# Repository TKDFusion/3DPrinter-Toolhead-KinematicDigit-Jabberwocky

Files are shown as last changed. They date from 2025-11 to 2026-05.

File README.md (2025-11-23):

# Jabberwocky

Jabberwocky Render

**JABBERWOCKY** has been engineered to meet the demanding requirements of filament changing units (FCUs) and multicolor changers. Its extruder is purpose-built to handle the rigorous load and unloading cycles of FCUs, utilizing a Bondtech compound drive gear in an offset configuration, paired with dual LDO non-threaded Orbiter gears for precise and reliable filament control.

The system offers a carefully optimized balance of torque and speed, along with increased surface contact on the filament to ensure stability and consistent feeding throughout operation.

Designed for maximum reliability and serviceability, the toolhead features a tool-free, hinged extruder mechanism, enabling fast and hassle-free maintenance.

Efficient thermal performance is delivered by high-static-pressure fans, ensuring airflow reaches critical areas, while the Phaetus Conch high-flow hotend enables smooth, consistent extrusion at volumes of up to 35 mm³/s.

For complete assembly instructions and additional technical details, please refer to our [Wiki](https://github.com/kinematicdigit/Jabberwocky/wiki).

Kits will be available through LDO Motor's Vendor Channels. Check your favourite vendor for the latest availability.

**OPTIONS**

Currently, there are three types of kits you can purchase.

- Prebuilt Jabberwocky Kit - This is fully assembled at the LDO facility and ready to install in your printer (after you print the correct mounting plate for your printer). It is intended to save time or for less effort. 
- Standard Jabberwocky Kit - Also sometimes referred to as DIY or Unassembled. This is the recommended kit for beginners to advanced users. Visit this [Wiki](https://github.com/kinematicdigit/Jabberwocky/wiki) link for instructions.
- Basic Jabberwocky Kit - This kit allows for self sourcing your own toolhead and tool-board. Great for users that might have the components. It gives flexibility for open development or advanced users who want to use different toolheads and different electronics. Examples like UHF Rapido or Revo toolheads are being actively developed/tested. Visit the discord channel to find out what third-party or independent users have created for the Basic Jabberwocky Kits.

For general support, please visit this [link](https://discord.gg/MPZ4cHm9gm) and visit the Jabberwocky channels. 

---
>**Acknowledgments and Thank You**
>
>*The Jabberwocky project commenced shortly after the release of ERCF V2 in November 2023, directly resulting from my contributions to the ERCF development team. I express my gratitude to my team members, particularly MoggieUK, who has been an exceptional ERCF partner, facilitating the exchange of ideas and addressing challenges related to multi-filament and filament-changing units. The realization of this project was contingent upon the substantial research and development support provided by Jason at LDO Motors. We dedicated numerous months to meticulous material selection, conceptual design, and component identification. Thanks to Dr. Róbert Lőrincz’s for technical assistance and comprehensive responses to my inquiries regarding stepper motors interfacing with ERCF, which also proved highly beneficial for this toolhead, as well as for his pioneering work with the Orbiter gears employed within it. Additionally, Fizzy, another ERCF team member, graciously contributed to the creation of the gorgeous wiki page and documentation, simplifying the user guide for assembling the kit. Finally, I would like to acknowledge the invaluable assistance provided by the many beta testers, who were instrumental in numerous revisions, improvements, and testing conducted during the testing phase.*

>
>*Happy Printing!*
>
>Terrance AKA kinematicdigit
>
Coffee fund donations are always welcome to help support my ongoing efforts. [Click here](https://www.paypal.com/donate/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) to donate. Thank-you!

Shield: [][cc-by-sa]

This work is licensed under a
[Creative Commons Attribution-ShareAlike 4.0 International License][cc-by-sa].

[][cc-by-sa]

[cc-by-sa]: http://creativecommons.org/licenses/by-sa/4.0/
[cc-by-sa-image]: https://licensebuttons.net/l/by-sa/4.0/88x31.png
[cc-by-sa-shield]: https://img.shields.io/badge/License-CC%20BY--SA%204.0-lightgrey.svg

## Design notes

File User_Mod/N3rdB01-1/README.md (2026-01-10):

# Jabberwocky Voron Tap Mods (User_Mod/<your-folder>)

This folder contains two Voron Tap adapter variants and an insert-placement diagram for the generic adapter. Use the files and instructions below to print, install, and (for the Chaotic Labs variant) modify wiring safely.

Files included
- `Jabberwocky CNC VORON TAP adapter.stl` — Generic Voron Tap adapter (requires two 3 mm inserts; see PDF)
- `Jabberwocky NH36_Mounting_Bracket for ChaoticLabCNCTapPobe.stl` — Chaotic Labs / NH36-specific mounting bracket and adapter (wiring-aware)
- `Jabberwocky CNC VORON TAP Adapter.pdf` — Insert location diagram (shows where to place the two 3 mm inserts)
- `README.md` — This file

Which file to use
- Use `Jabberwocky CNC VORON TAP adapter.stl` for a standard Voron Tap installation. This model requires two 3 mm inserts per the PDF.
- Use `Jabberwocky NH36_Mounting_Bracket for ChaoticLabCNCTapPobe.stl` when installing on a Chaotic Labs Voron tap where the Chaotic wiring interferes with the generic adapter. This variant requires wiring modification per the NH36 wiring diagram (see “Wiring modification” below).

Important safety note — wiring & power
- Do not perform any wiring work while the machine is powered or connected to mains.
- If you are not comfortable working with electronics, ask a qualified person to do the wiring changes.
- The Chaotic Labs variant requires wiring changes according to the NH36 wiring diagram. This README contains high-level guidance; explicit wiring steps will be added once the NH36 wiring diagram / pin mapping is reviewed.

Wiring modification — required reference documents
To modify the TAP cable for the NiteHawk (NH36) board you will need both documents:
- NiteHawk-36 toolboard documentation (Nightawk 36 board wiring / pinout):
  https://docs.ldomotors.com/en/Toolboard/nitehawk-36
- CNC Tap Build Guide (ChaoticLab TAP probe manual):
  https://github.com/Chaoticlab/CNC-Tap-for-Voron/blob/951225ebef3c1753b8fc599a90948c430e2c5943/Manual/CNC_VORON_TAP_V2_BUILD_GUIDE_20240222.pdf

How to use these documents together
1. Open both documents side-by-side (or print the relevant pages). Identify:
   - On the TAP manual: connector pinout for the probe end and the wire colors used in the TAP cable.
   - On the NiteHawk-36 doc: the connector pinout for the NH36 input (which pins accept probe signals, power, ground, etc.).
2. Document current wiring:
   - Photograph the existing TAP connector and cable.
   - Label each wire (numbered or color-coded) so you can map original → new locations.
3. Compare pinouts and plan the mapping:
   - For each TAP wire, determine whether it must be moved to a different pin on the NH36, require a different connector, or requires splice/retermination.
4. Prepare tools and materials:
   - Soldering iron and solder or quality crimp connectors
   - Heat shrink tubing
   - Multimeter
   - Tie wraps / adhesive mounts to secure wires
   - Replacement connector housings if required (confirm exact part number from the docs)
5. Implement the mapping carefully (power OFF):
   - Cut and reterminate wires only after confirming your mapping.
   - Use proper strain relief and insulation.
   - Securely fasten the wiring away from moving parts.
6. Verify before powering:
   - Use a continuity/multimeter check to confirm each TAP signal/power/ground is connected to the intended NH36 pin.
   - Confirm no shorts between power and ground.
7. Power on and test:
   - Power the system and test probe functions in a safe mode (manual probe tests, reduced-power checks).
   - Watch for unexpected heating, smoke, or incorrect voltages — power off immediately if detected.

Wiring-modification checklist (safety)
- [ ] Power is disconnected before any work begins.
- [ ] Wires are labelled and photographed before cutting.
- [ ] You have the correct connector housings/pins (if replacing).
- [ ] Solder joints/crimps are insulated with heat shrink.
- [ ] Continuity and voltage checks done before finalizing.
- [ ] Wiring is secured away from moving parts.

Print settings (recommended starting point)
- Material: PLA or PETG (use PETG if the part will see elevated temps)
- Layer height: 0.20 mm
- Infill: 15–25%
- Perimeters (walls): 2–3
- Print temperature: 200–220 °C (PLA) / 230–250 °C (PETG)
- Bed temperature: 60 °C (PLA) / 70–80 °C (PETG)
- Supports: minimal; enable where model shows overhangs >45°
- Orientation: Print the adapter with the main flat face on the bed (see preview in slicer)

Bed height & printer setup — IMPORTANT (applies to both variants)
- Installing these adapters often requires increased clearance between the print bed and the tap/nozzle assembly.
- For example, on an Ender 5 Plus with a standard bed a solid spacer and raising the bed to >23 mm were required to achieve correct clearance.
- After changing bed height, re-level the bed and verify Z offsets and probe/endstop behavior to avoid crashes.

Inserts — the generic adapter
- The generic `Jabberwocky CNC VORON TAP adapter.stl` requires two 3 mm inserts. See `Jabberwocky CNC VORON TAP Adapter.pdf` for exact hole locations.
- Installation notes for heat-set or press-fit inserts are included in this README.

Assembly — generic adapter
1. Clean printed parts and remove supports.
2. Install the two 3 mm inserts per `Jabberwocky CNC VORON TAP Adapter.pdf`.
3. Align adapter to the Voron Tap mount and secure with M3 screws (hand-tighten; do not overtighten).
4. Verify clearance with wiring and moving parts; re-check after first test run.

Chaotic Labs variant — overview and wiring modification
- Purpose: `Jabberwocky NH36_Mounting_Bracket for ChaoticLabCNCTapPobe.stl` repositions/mounts to avoid Chaotic Labs wiring routing.
- Follow the steps above using the two docs linked earlier to map and modify the TAP cable.

Troubleshooting
- Part won’t seat: confirm slicer scaling = 100% and measure printed dimensions. If holes are too small, open by +0.1–0.3 mm.
- Inserts won’t seat: for heat‑set inserts reduce temperature slightly or pre-warm part; for press-fit try reaming slightly larger.
- Wiring issue after install: power down, re-check wire labels and continuity. If unsure, revert changes and get assistance.
- Bed/clearance issues: if your bed requires significant raising, re-check endstop/probe offsets and Z travel limits before applying power.

Files to include in a release
- Include the two .stl files and `Jabberwocky CNC VORON TAP Adapter.pdf`.
- Add photos of the installed parts (top/bottom) and a short installation video if possible.

Credits & license
- Designer: <Your Name / GitHub handle>
- Contributors: list as needed
- License: See repository root LICENSE. If none, consider adding a license (e.g., CC BY-SA 4.0 for models).

Contact / support
- Open an issue in this repo or contact @<your-github-handle> with questions or test-fit reports.

Changelog
- v1.0 — Initial release: `Jabberwocky CNC VORON TAP adapter.stl`, `Jabberwocky NH36_Mounting_Bracket for ChaoticLabCNCTapPobe.stl`, `Jabberwocky CNC VORON TAP Adapter.pdf`, README (updated with bed height and wiring doc links)

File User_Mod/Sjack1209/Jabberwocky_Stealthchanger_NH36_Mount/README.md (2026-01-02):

# Jabberwocky Stealthchanger NH36 Mount

This was designed to properly mount the NiteHawk36 to the Jabberwocky Toolhead while using the Stealtchanger backplate and optical sensor. 

The spacer is not required, but without it the mount sits directly against the back of the extruder stepper.

This is a remix of [https://github.com/DraftShift/StealthChanger/tree/main/UserMods/TheSin-/PCB36_Mount/PCBMount.stl] 
 
<table>
  <tr>
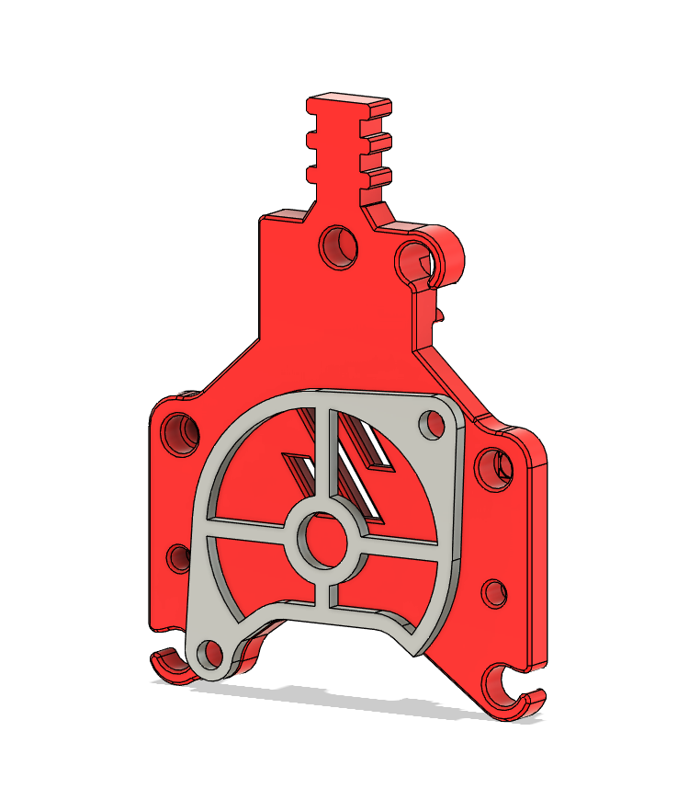
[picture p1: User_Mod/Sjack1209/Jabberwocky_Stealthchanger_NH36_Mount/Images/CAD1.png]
    <td></td>
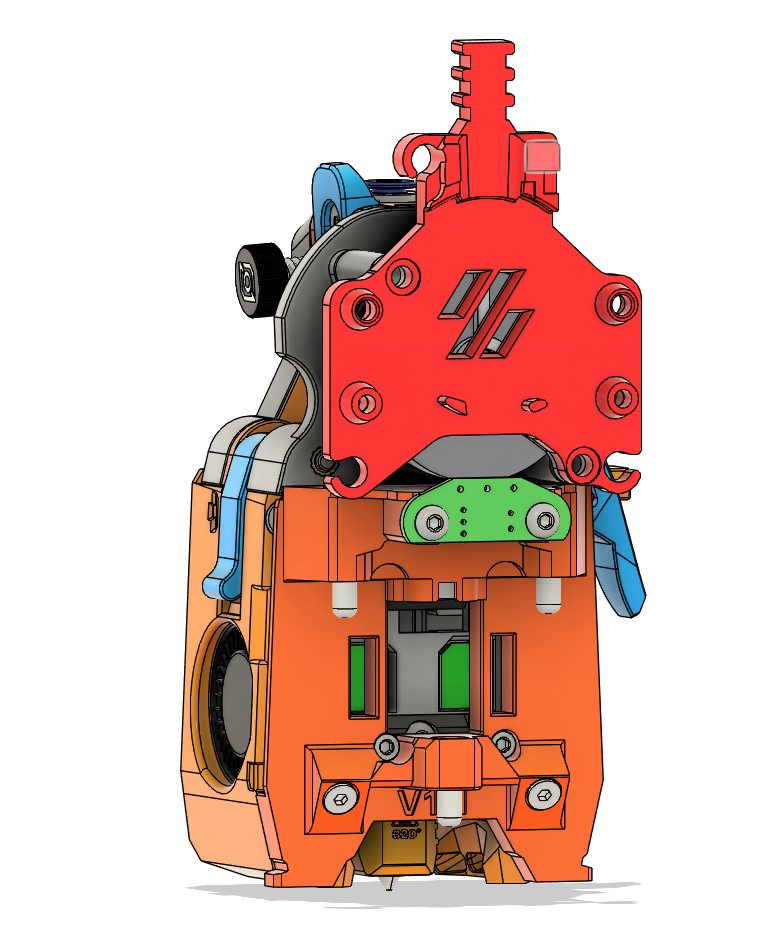
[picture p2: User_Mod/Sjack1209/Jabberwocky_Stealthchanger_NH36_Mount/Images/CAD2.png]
    <td></td>
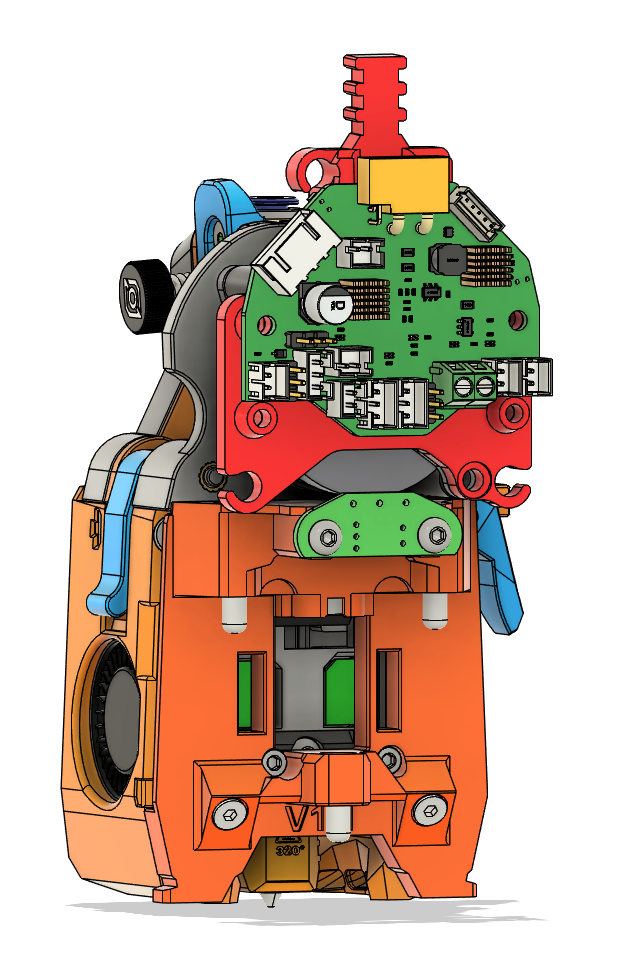
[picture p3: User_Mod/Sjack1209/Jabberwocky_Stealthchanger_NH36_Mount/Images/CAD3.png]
    <td></td>
  </tr>
  <tr>
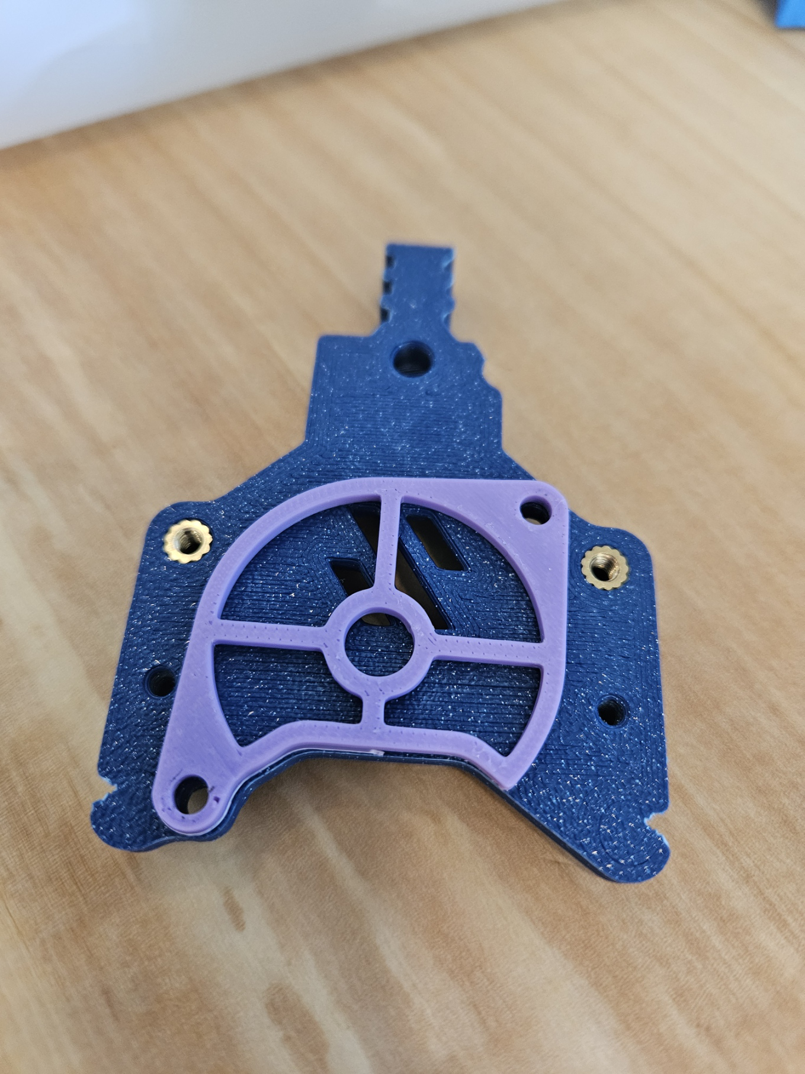
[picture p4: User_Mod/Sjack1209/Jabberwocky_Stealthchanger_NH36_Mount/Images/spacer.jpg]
    <td></td>
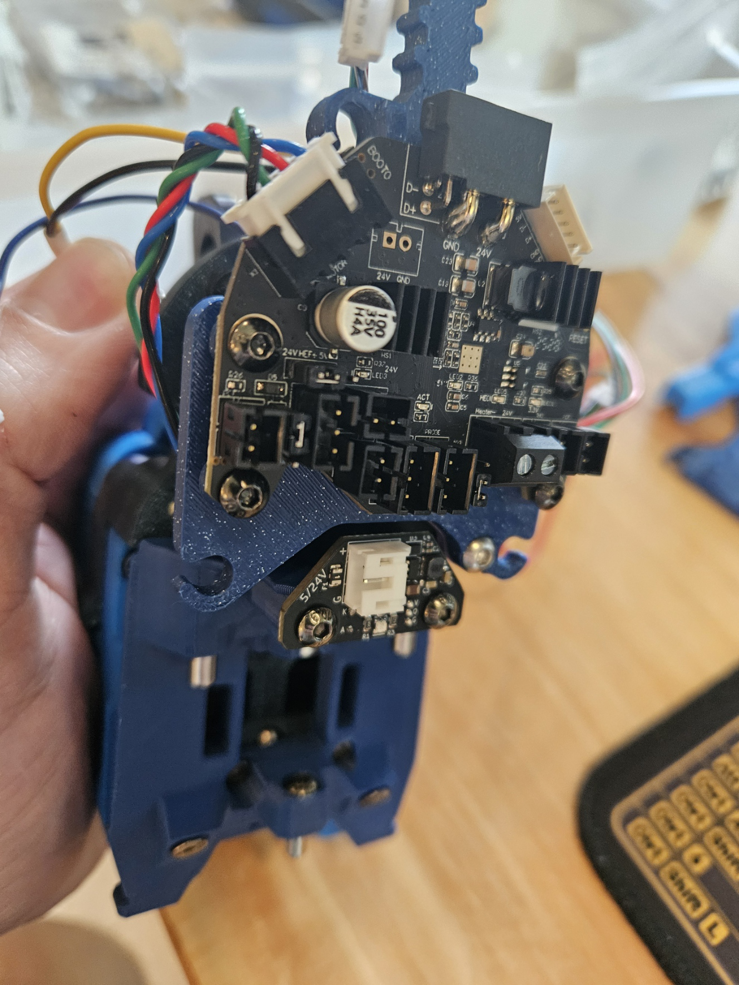
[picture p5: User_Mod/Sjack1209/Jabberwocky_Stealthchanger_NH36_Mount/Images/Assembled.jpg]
    <td></td>
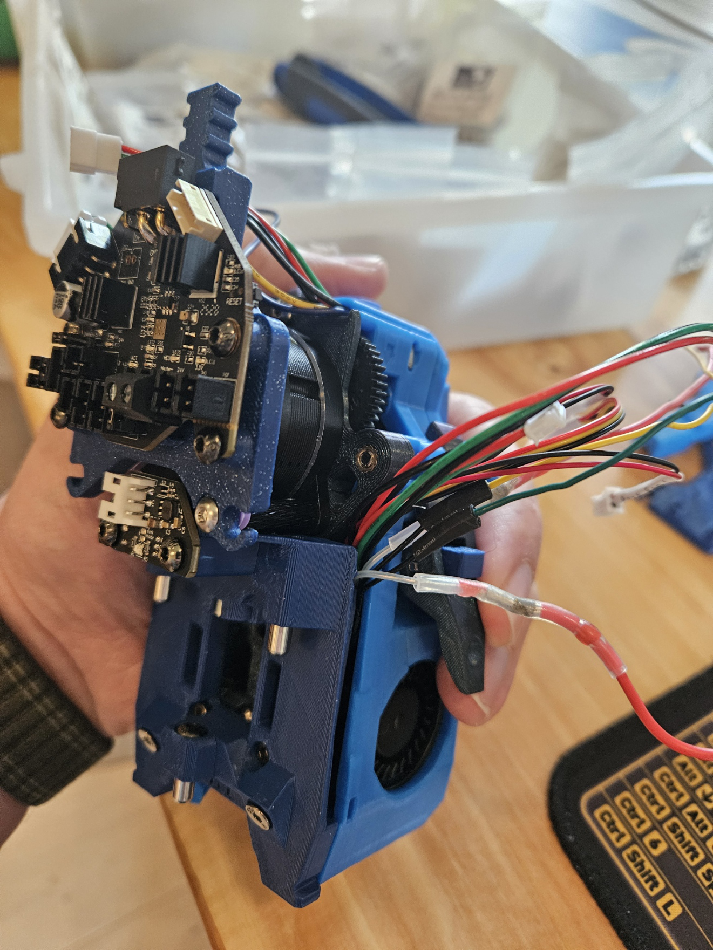
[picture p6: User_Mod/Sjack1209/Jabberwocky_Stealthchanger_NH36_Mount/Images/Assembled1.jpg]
	<td></td>
  </tr>
</table>

## Printing

Use standard voron print settings. 4 walls, 5 top & bottom laters, 40% infill.

## Installation

insert 2 heatset inserts into the back of the mount 

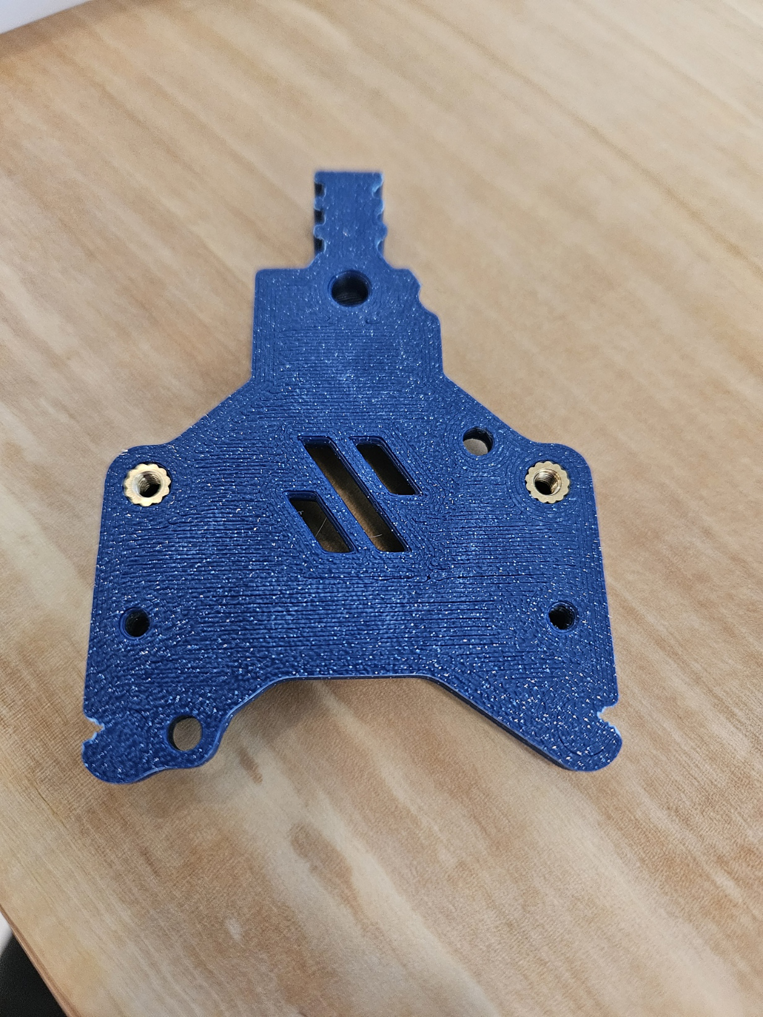
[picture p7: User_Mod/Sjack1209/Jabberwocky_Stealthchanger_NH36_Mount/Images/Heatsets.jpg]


Then attach the mount and spacer to the Toolhead using 2 M3x10 or M3x12 BHCS 

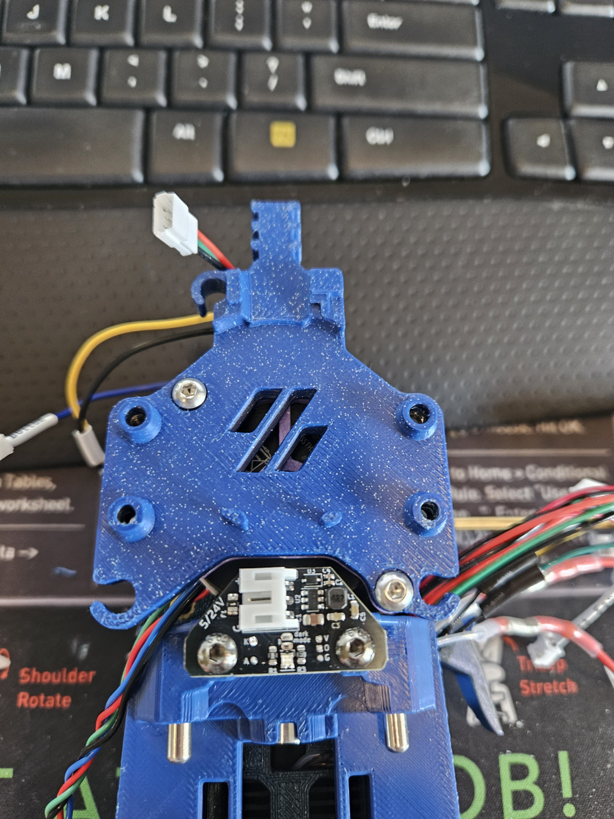
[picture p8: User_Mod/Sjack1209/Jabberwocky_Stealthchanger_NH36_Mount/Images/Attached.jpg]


Next, attach the NH36 with either 2 or 4 M3x8 BHCS



## Bill of Materials (BOM)

qty 2 M3 heatset inserts

## Credits

Thanks to TheSin- for the original PCBMount file that was used.

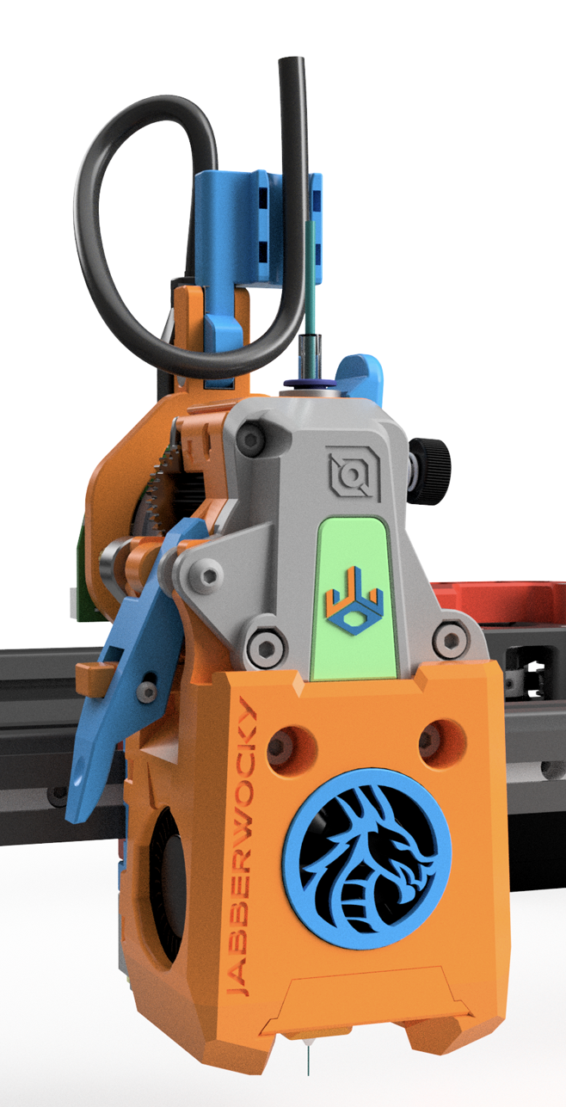
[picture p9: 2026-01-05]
Images/Promo Pic2.png

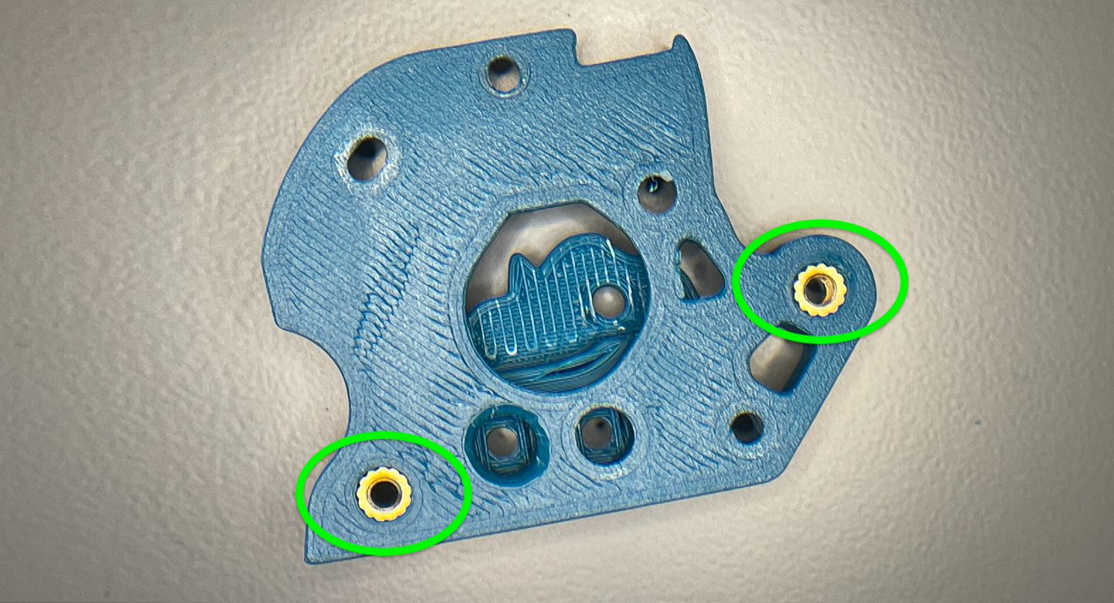
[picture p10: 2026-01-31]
Images/Extruder/Extruder-1_82.png

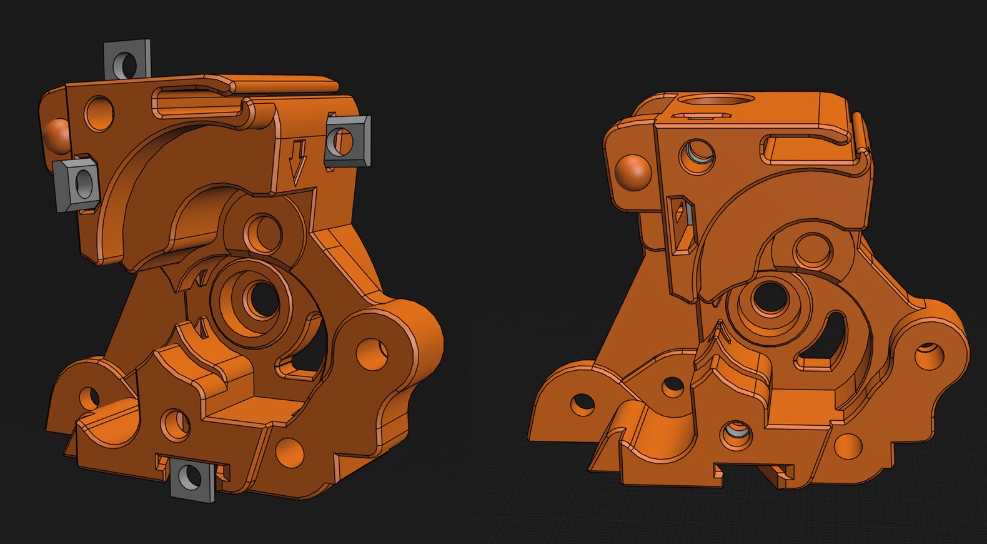
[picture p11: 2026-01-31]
Images/Extruder/Extruder 2.jpg

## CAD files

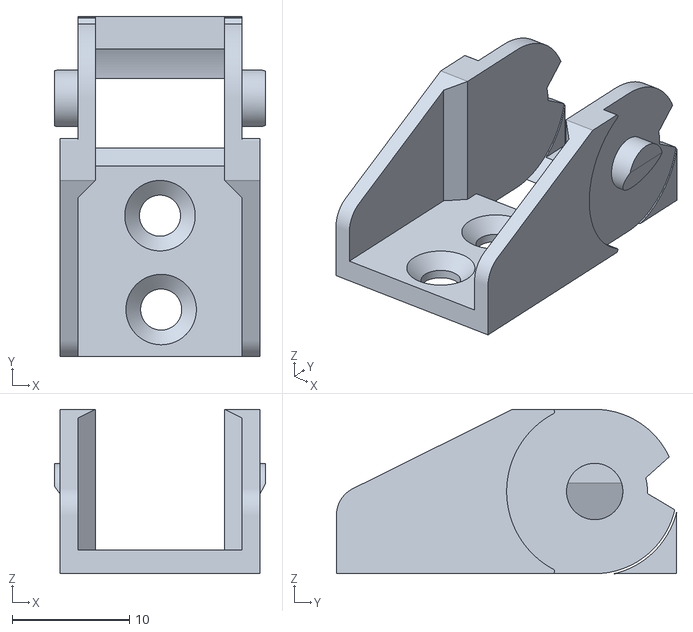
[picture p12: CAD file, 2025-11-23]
Development-testing/drag_chain_support/Chain_Anchor_Fixed_2_hole.stl
18.0 x 29.0 x 14.0

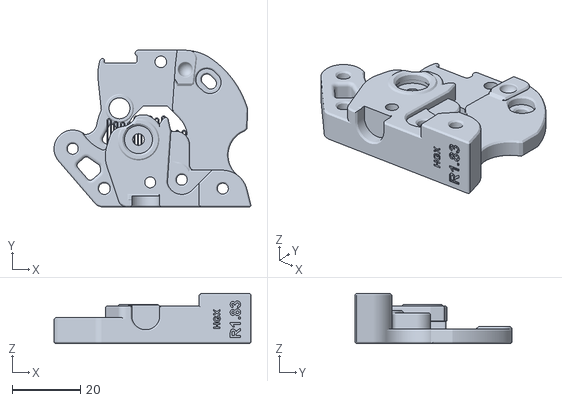
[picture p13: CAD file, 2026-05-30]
Development-testing/HGX-Drive-gear/[a] Motor_Mount_HGX.stl
57.8 x 46.0 x 14.7

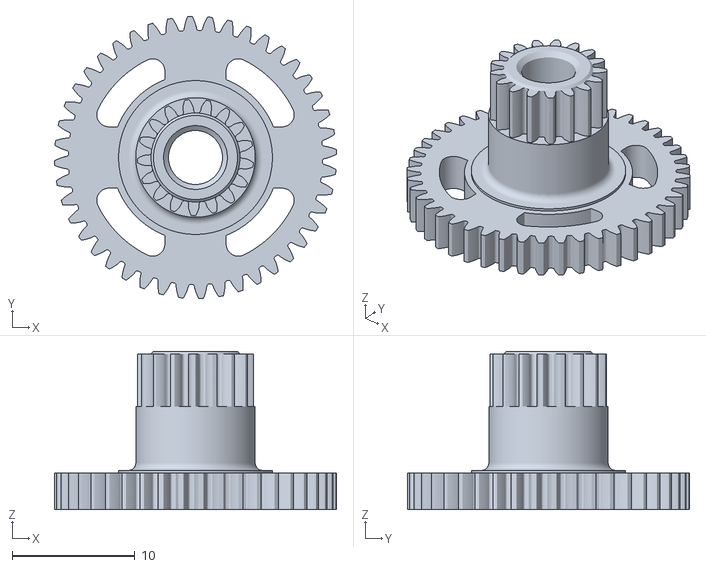
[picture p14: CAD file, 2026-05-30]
Development-testing/printable_drive_gear/Printabe_drive_gear.stl
23.0 x 23.0 x 12.9

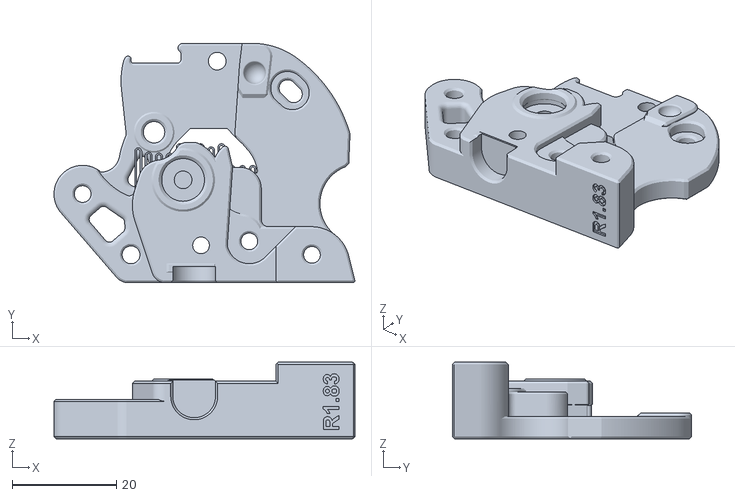
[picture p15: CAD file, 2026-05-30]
Development-testing/R1.83/[a] Motor_Mount.stl
57.8 x 46.0 x 14.7

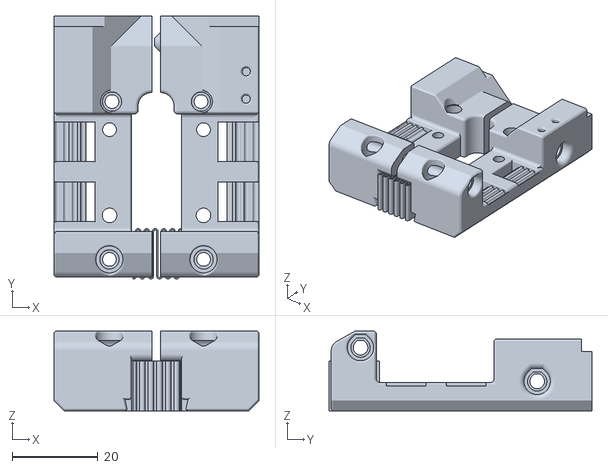
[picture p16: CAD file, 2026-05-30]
Development-testing/SplitMount_MKIV/MGN12-Split_mount_MK4_9mm.stl
47.8 x 61.3 x 18.6

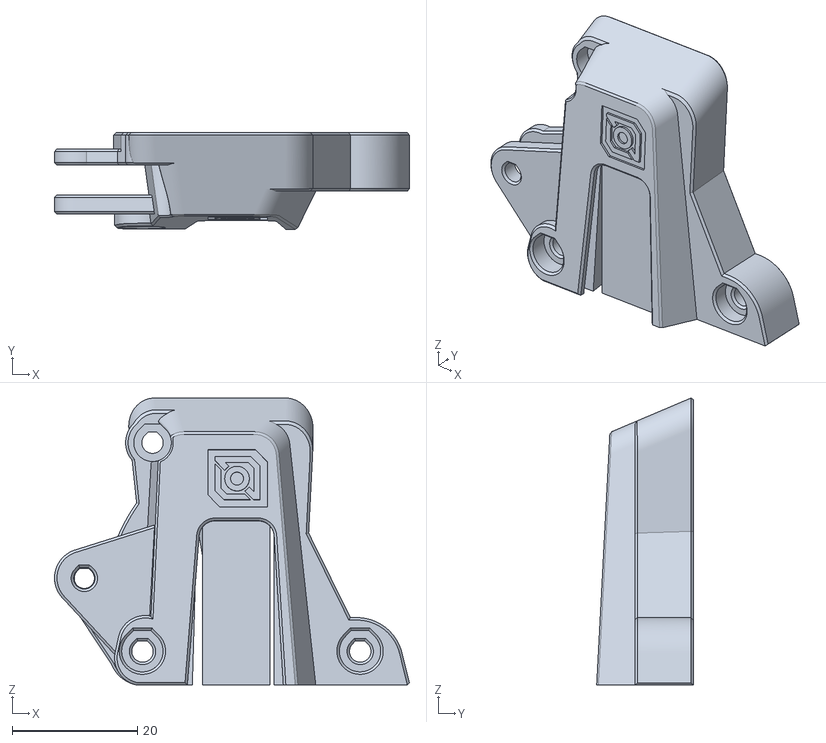
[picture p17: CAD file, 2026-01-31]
Development-testing/V82-RC4/2. Extruder Front Cover/[a] Front_Body.stl
56.7 x 15.4 x 45.8

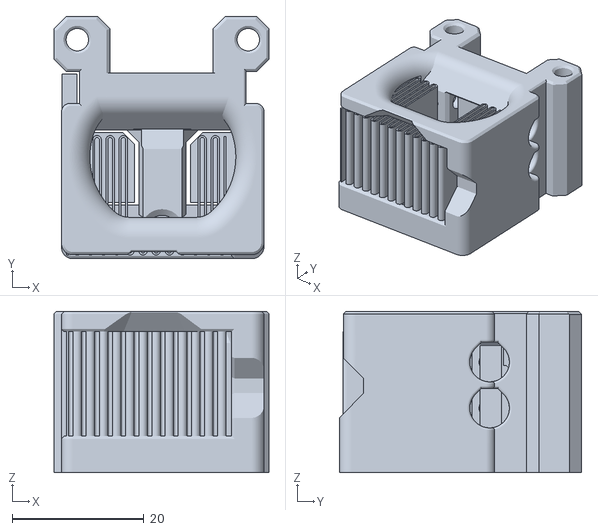
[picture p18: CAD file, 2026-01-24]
Development-testing/V82-RC4/3. Lower Toolhead/[b] Conch_Mount.stl
32.7 x 36.9 x 24.5

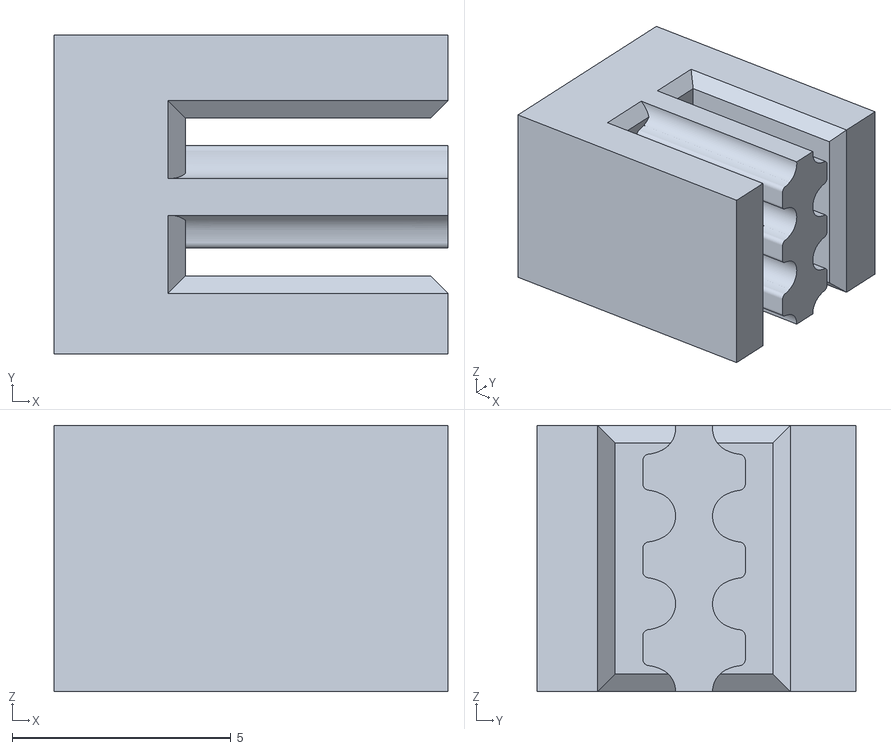
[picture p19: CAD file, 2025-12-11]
Development-testing/V82-RC4/4. Voron 24 - Trident Mounting/belt-lock.stl
9.00 x 7.29 x 6.08

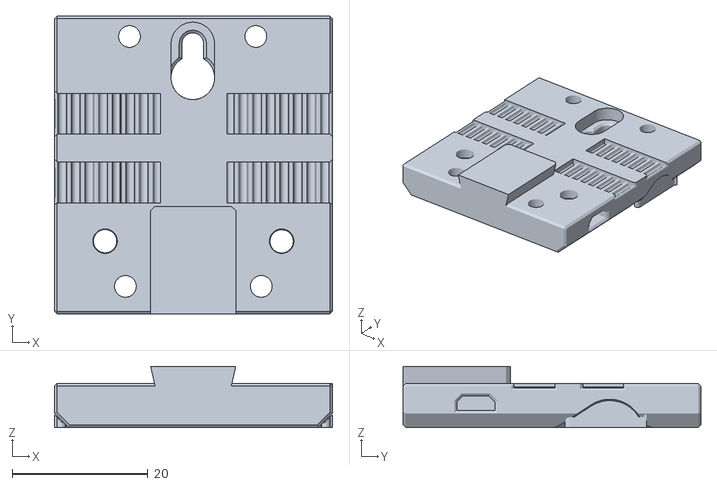
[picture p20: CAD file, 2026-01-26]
Development-testing/V82-RC4/4. Voron 24 - Trident Mounting/split_mount_6mm_belt/MGN12H_Mount_Block_Front.stl
41.0 x 43.9 x 9.03

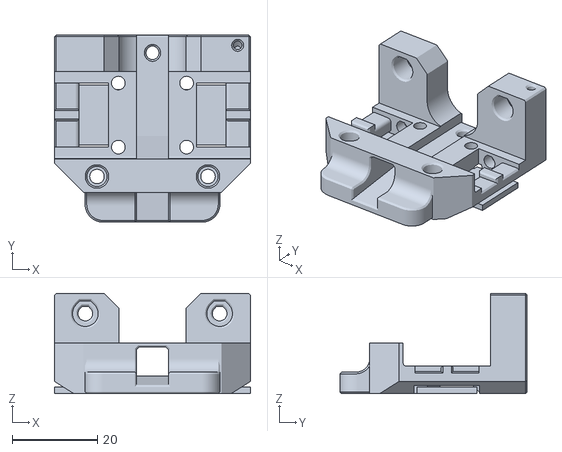
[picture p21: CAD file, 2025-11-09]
Development-testing/V82-RC4/Other_Mounts/Micron/MGN9H_Mount.stl
45.9 x 43.9 x 23.5

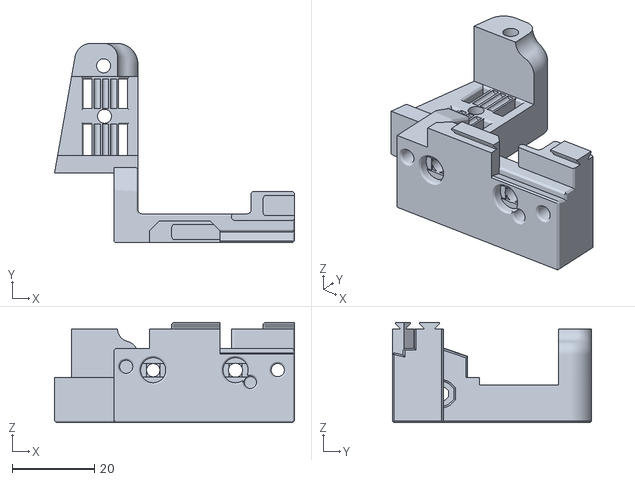
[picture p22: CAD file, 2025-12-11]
Development-testing/V82-RC4/Other_Mounts/Switchwire/SW_Carriage_Right.stl
58.3 x 48.4 x 24.3

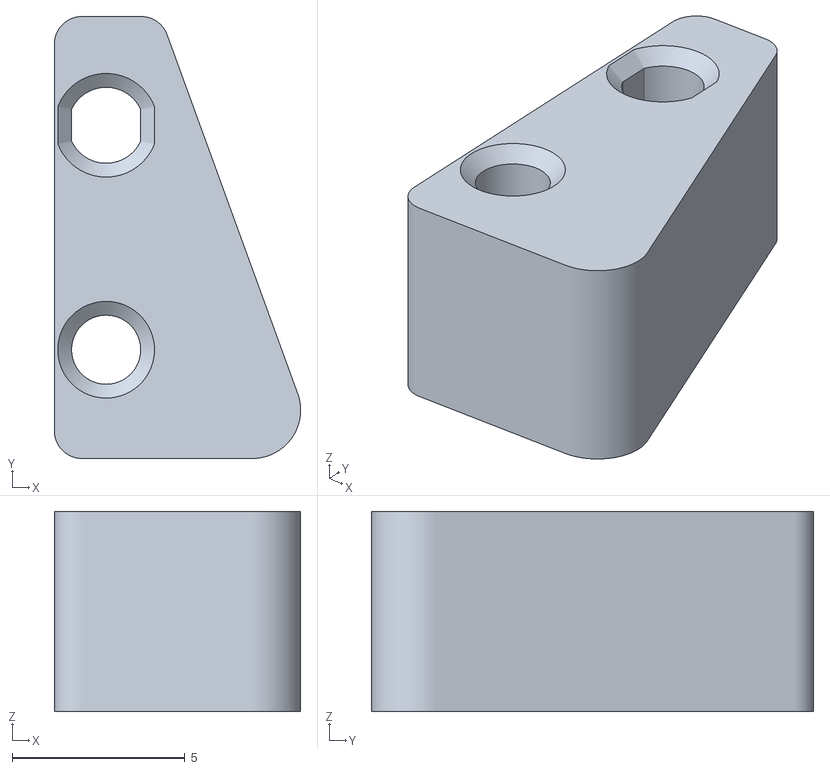
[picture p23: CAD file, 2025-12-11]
Development-testing/V82-RC4/Other_Mounts/X-Sensorless_block_small.stl
7.13 x 12.8 x 5.80

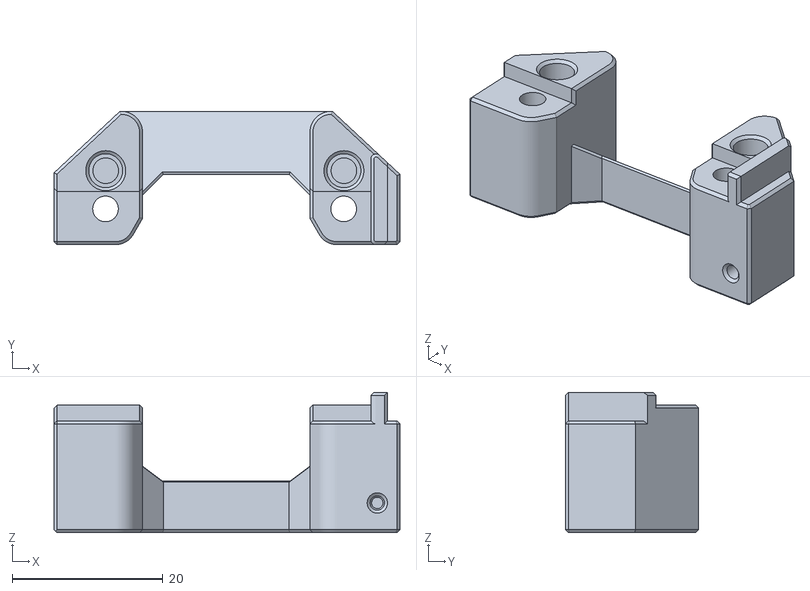
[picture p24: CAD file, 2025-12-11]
Development-testing/V82-RC4/Probes/Carto-Beacon/Carto-Beacon_Mount_Adapter.stl
45.9 x 17.7 x 18.6

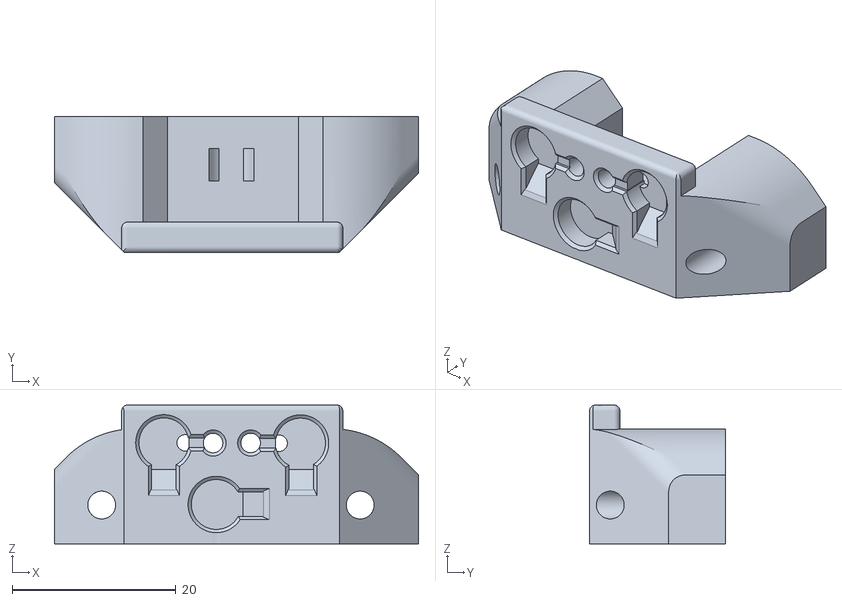
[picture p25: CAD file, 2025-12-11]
Development-testing/V82-RC4/Probes/Klicky/Jabberwocky_Klicky.stl
44.5 x 16.6 x 17.0

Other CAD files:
Development-testing/V82-RC4/Probes/PCB-Klicky/JW_PCB_klicky_mount_adapter.stl
Development-testing/V82-RC4/Tools/Carrot_Puller_Case.stl
STLs/2. Extruder Front Cover/NH36_Mount_Optional_3_column_Support/Hex_standoff-self-thread.stl
STLs/4. Voron 24 - Trident Mounting/split_mount_9mm_belt/MGN12H_Mount_Block_Front_9mm.stl
Development-testing/HGX-Drive-gear/Mid-Body-Base_HGX-ECAS.stl
Development-testing/R1.83/[ab] Guidler.stl
Development-testing/SplitMount_MKIV/MGN12-Split_mount_MK4_6mm.stl
Development-testing/V82-RC4/1. Extruder/Mid_Body_ECAS.stl
Development-testing/V82-RC4/1. Extruder/[a] Motor_Mount.stl
Development-testing/V82-RC4/1. Extruder/[ab] Guidler.stl
Development-testing/V82-RC4/2. Extruder Front Cover/Front_Body_Emount.stl
Development-testing/V82-RC4/2. Extruder Front Cover/NH36_Mounting_Bracket.stl
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

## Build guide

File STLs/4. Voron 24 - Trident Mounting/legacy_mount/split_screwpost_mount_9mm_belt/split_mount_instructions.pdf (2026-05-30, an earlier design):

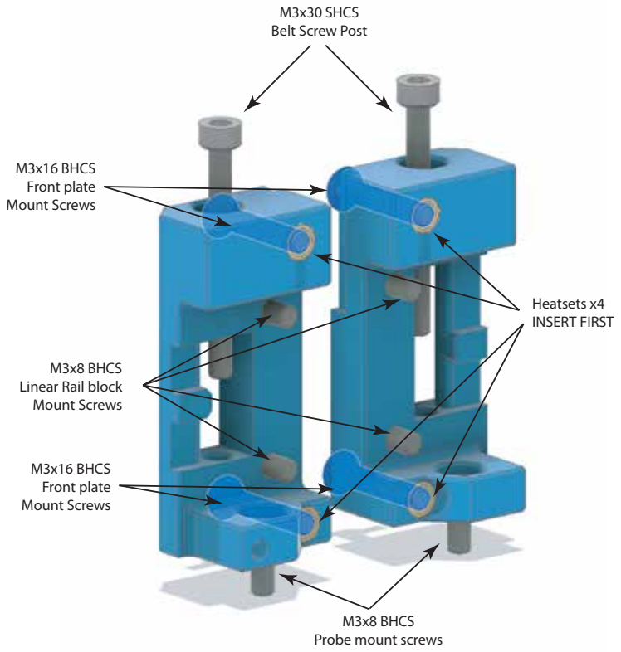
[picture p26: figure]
M3x30 SHCS Belt Screw Post; M3x16 BHCS Front plate Mount Screws; Heatsets x4 INSERT FIRST; M3x8 BHCS Linear Rail block Mount Screws; M3x8 BHCS Probe mount screws

Choose the correct one for your system. 1.7mm should work with most systems, but due to inconsistencies between brands and manufacturers, you may need to use a dierent one. If you take your belts and fold it over with teeth meshing into each other, you can measure with digital calipers and should have a number of 2.3mm as your baseline.

- 1.5mm has been found to work best with economical HWIN clones like Fysetc and if your belts are thinner than the baseline of 2.3mm
- 1.7mm works with HWIN, LDO, and Genuine Gates GT2 belts.
- 2.0mm is intended for Genuine Gates GT3 or thicker prole belts.

# Jabberwocky Split Mount Instructions

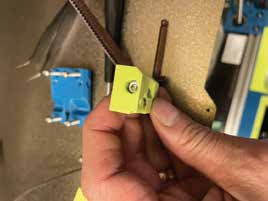
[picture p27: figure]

Start by Inserting heatset (look at hadware diagram)
Insert M3x30mm SHCS at the top.

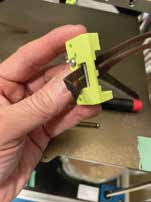
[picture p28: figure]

Loop belt from behind,
and loop back in.
Belt teeth will lock into
each other

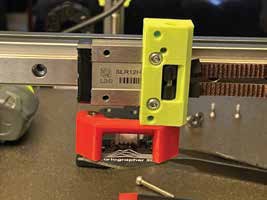
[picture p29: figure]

Mount probe mount, then
install two of the rail
mount screws.

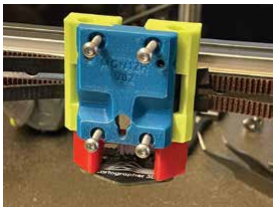
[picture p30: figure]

Final step is add the front retaining platethat keeps
the mount secure.

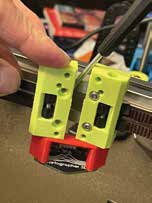
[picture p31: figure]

Repeat the second step on the other side, and turn the mount out slightly so you can install it on the probe mount.

Turn it into place, and start to tighten down the screws.

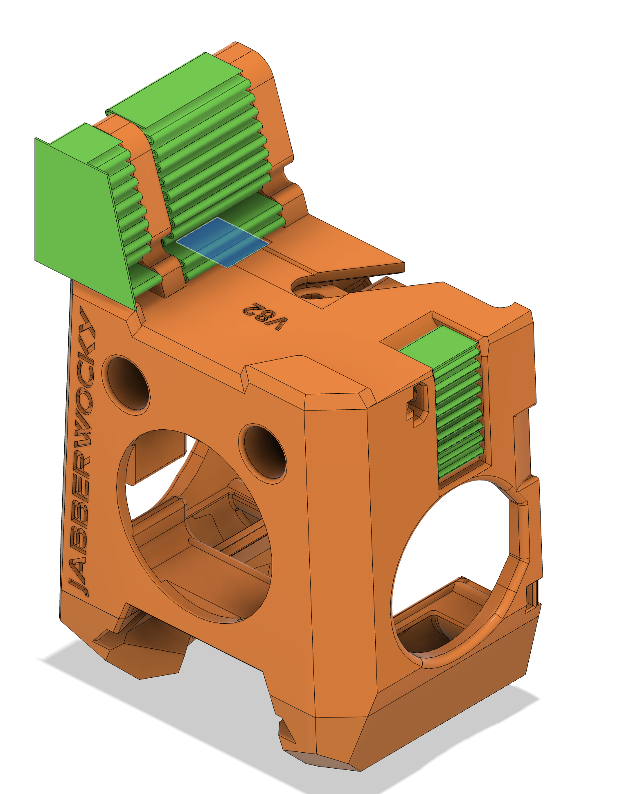
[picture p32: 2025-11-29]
Images/printsupports/shroud.png

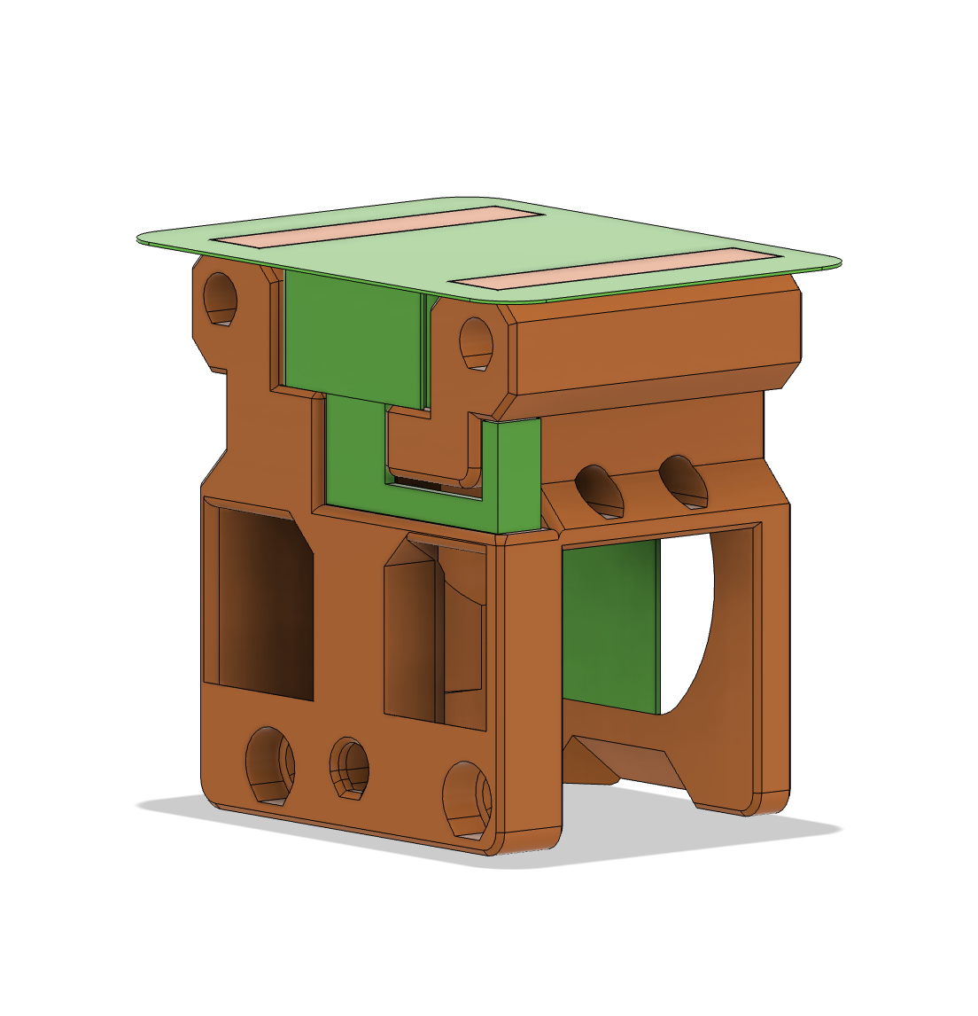
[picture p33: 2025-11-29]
Images/printsupports/conch.png

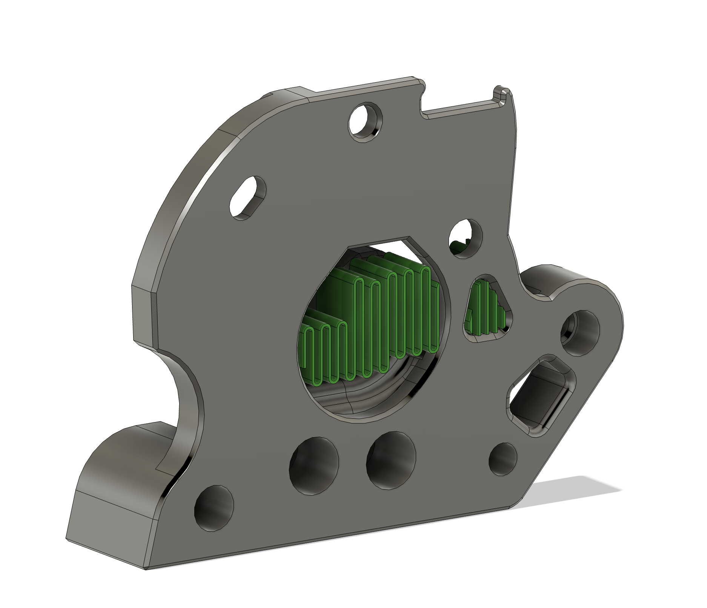
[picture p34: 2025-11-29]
Images/printsupports/motormount.png

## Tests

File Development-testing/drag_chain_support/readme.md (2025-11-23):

**CABLE CHAIN SUPPORT FOR JABBERWOCKY**
This is still under testing.

Cable/Drag Chain support is now ready for active testing for Jabberwocky. The mod allows for stock cable chains to be used, or if you feel like getting fancy, I've designed new cable chains that limit the bend radius to 40° or a minimum bend diameter of 50mm to avoid the break point of most wires, which is around 40 mm. 

The mod requires a horizontal adapter that converts the XY Joint to allow for a horizontal chain. A new electronics mount that accepts the horizontal cable chain that has a limiter to allow it to hinge and open when servicing the toolhead. You will need to use two-hole anchors for interfacing with JW so it pivots properly, but there are several cable chain anchors to select to make yours work if you're using the three-hole cable chains that step down to two. 

Start with the fixed wire channel (currently will work with 250-350 builds). and either use your old cable chains and attach directly to the fixed wire channel, or count how many links you need and print the required amount. 

The clips twist in or use a table to push them in, but I recommend just twisting one side and leaving the other open to load wire. When chains are assembled, work them around the radius of the chain to get it working smoothly. It will be stiff at first, but it will get smoother the more you work it.

Please visit the JW discord channel for any other questions.

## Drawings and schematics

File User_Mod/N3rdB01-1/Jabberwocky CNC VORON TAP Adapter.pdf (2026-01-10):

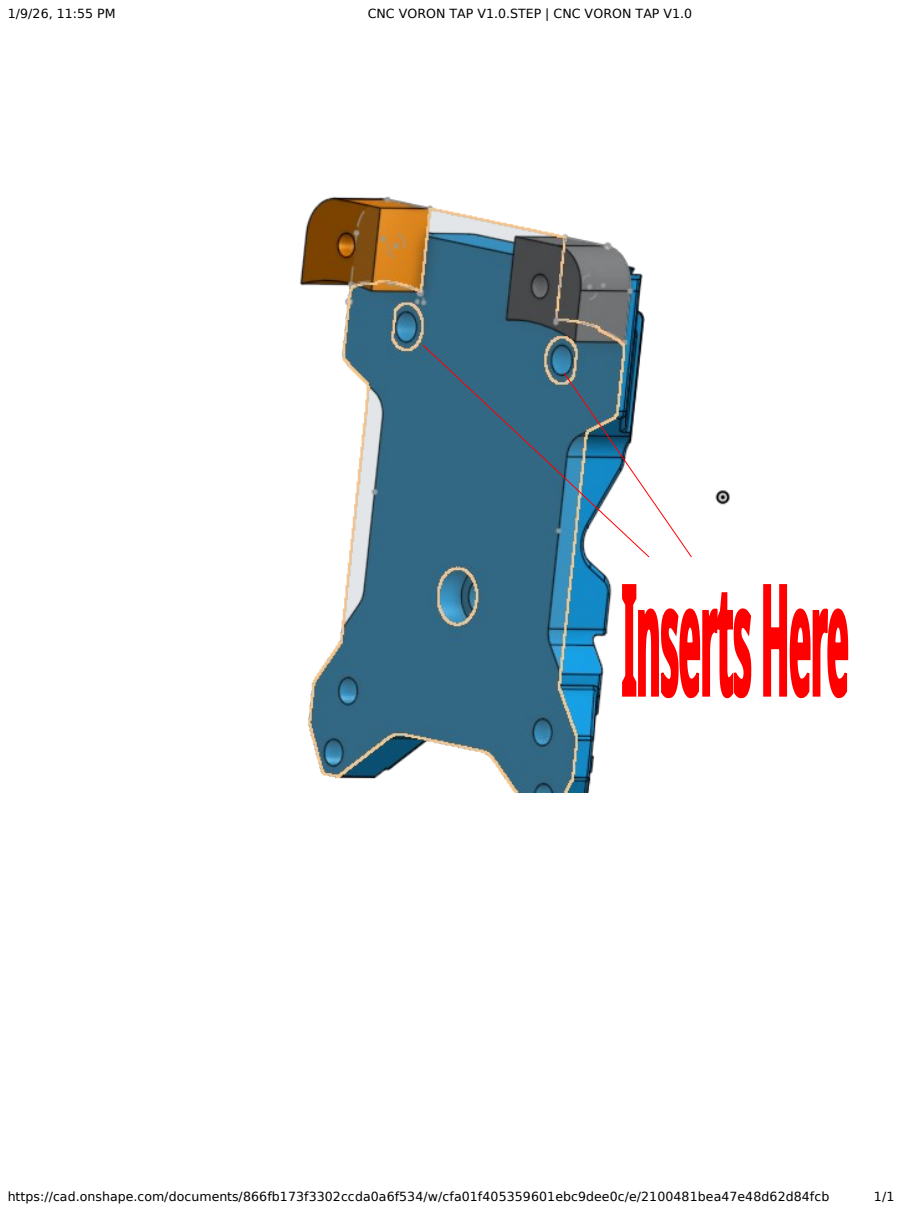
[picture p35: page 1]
CNC VORON TAP V1.0.STEP | CNC VORON TAP V1.0; https://cad.onshape.com/documents/866fb173f3302ccda0a6f534/w/cfa01f405359601ebc9dee0c/e/2100481bea47e48d62d84fcb

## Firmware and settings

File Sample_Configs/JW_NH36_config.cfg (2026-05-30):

#####################################################################
#   Extruder
#####################################################################
[extruder]
step_pin: nhk:gpio23
dir_pin: !nhk:gpio24
enable_pin: !nhk:gpio25
microsteps: 16
rotation_distance: 35.2												#Be sure to calibrate
gear_ratio: 44:8, 25:17
nozzle_diameter: 0.400
filament_diameter: 1.750
heater_pin: nhk:gpio9
sensor_type: Generic 3950
sensor_pin: nhk:gpio29
pullup_resistor: 2200
#control: pid                                                        # Do PID calibration after initial checks
#pid_Kp: 28.182
#pid_Ki: 1.978
#pid_Kd: 100.397
min_temp: 0
max_temp: 315
min_extrude_temp: 170
max_extrude_only_distance: 1000                                     
max_extrude_cross_section: 30                                       
pressure_advance: 0.052                                             #Be sure to calibrate
pressure_advance_smooth_time: 0.040

[tmc2209 extruder]
uart_pin: nhk:gpio0
tx_pin: nhk:gpio1
interpolate: false
run_current: 0.65     #.55 minimum DO NOT EXCEED .7A as it will cause excess heat.
sense_resistor: 0.100
stealthchop_threshold: 0
driver_TBL: 1
driver_TOFF: 3
driver_HSTRT: 0
driver_HEND: 3                   

#####################################################################
#   Fans
#####################################################################
## PCF
[fan]
pin: nhk:gpio6
kick_start_time: .3
off_below: 0.1


## HEF
[heater_fan hotend_fan]
pin: nhk:gpio5
tachometer_pin: nhk:gpio16
tachometer_ppr: 2
max_power: 1.0
kick_start_time: .1
heater: extruder
heater_temp: 50.0
fan_speed: .6

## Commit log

2025-11-03 Initial prototype Klicky-NG mount and dock bracket for Voron 2.4
    [KlickyNG Jabberwocky Mount.f3z]
2025-11-09 Mount updates
    [JW-MGN9C-H-Clamp_x2.stl, JW-MGN9C-H-Mount.stl, MGN12H_Mount_Block_2mm_split.stl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]
2025-11-11 added additional depths for belt mounts
    [MGN12H_Mount_Block_1.5mm_split.stl, MGN12H_Mount_Block_1.7mm_split.stl]
2025-11-19 Shroud V82 update
    Added a few cross supports to the print supports to make it play nicer on bridges.
    [GuiIdler_V82.stl, LED_Carrier_LDO.stl, MGN12H_Mount_Block-9mm.stl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]
2025-11-23 Cable Chain Support
    Cable Chain support is currently experimental.
    [40_Drag_Chain_Clip.stl, 40_Drag_Chain_Link.stl, Chain_Anchor_Fixed_2_hole.stl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]
2025-11-23 Add readme for cable chain support in Jabberwocky
    Added initial documentation for cable chain support in Jabberwocky, detailing features, requirements, and assembly instructions.
2025-11-29 print support images
2025-12-04 RC3 Update
    [Bearing Tool-Motor_V82RC3.stl, Bearing Tool.stl, Mid-Body-Base_V82RC3.stl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]
2025-12-06 Housekeeping
    Cleaning up files in the Developing-testing folder. Added instructions for the split-screwpost-mount.
    [GuiIdler_V82.stl, MGN12H_Mount_Block-9mm.stl, MGN12H_Mount_Block_1.5mm_split.stl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]
2025-12-11 V82RC4 Folder creation
    Combined repo with revised files replacing old one.
    [Bearing Tool-Motor_V82RC3.stl, Bearing Tool-Motor_cap.stl, Bearing Tool.stl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]
2025-12-30 NH36 mount with Stealthchanger
    Mod to mount NH36 when using Stealthchanger Backplate
    [Jabberwocky_Stealthchanger_NH36_Mount.stl, Jabberwocky_Stealthchanger_NH36_Mount_Spacer.stl, Jabberwocky_Stealthchanger_NH36_Mount_and_Spacer.step]
2025-12-31 Fixed naming errors
    [Jabberwocky_Stealthchanger_NH36_Mount.stl, Jabberwocky_Stealthchanger_NH36_Mount_Spacer.stl, Jabberwocky_Stealthchanger_NH36_Mount_and_Spacer.step]
2026-01-10 Cleaned up folders
    [Hex Fan Grill.3mf, Hex Shroud Body.3mf, Hex_Diffuser.3mf]
2026-01-24 Update [b] Conch_Mount.stl
    Easier to print version. No change to the mount, just using wave print supports now.
    [[b] Conch_Mount.stl]
2026-01-26 updates to the mounting systems
    New test Split Mount system with 4 points of security for 6mm, and 2 points for 9mm belts.
    Designed for AWD and high tension environments.
    [MGN12H_Mount_Block-9mm.stl, MGN12H_Mount_Block_1.5mm_split.stl, MGN12H_Mount_Block_1.7mm_split.stl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]
2026-01-27 Add readme for new split mount design
    Introduced a new split mount design that simplifies installation and accommodates various belt thicknesses.
2026-01-31 Added V82 Documentation
    Added V82 Assembly Instructions and some file management clean up.
    [[a] Front_Body.stl, washer_pre_V78.stl]
2026-01-31 Revise readme with updates on component changes
    Updated descriptions for various components, including the Conch Mount and Mid Body ECAS, to reflect corrections and improvements.
2026-01-31 Corrections to documentation
    Some additional callout images, printing instructions, and corrections to mistakes in the docs.
2026-05-18 adds an adapter for chunky alpaca tensioners
    [Chunky_Alpaca_Adapter.stl]
2026-05-30 Updates
    Updates, mostly development testing items.
    New split mount parts with integrated Cartographer/Beacon adapter.
    [18.5mm-Standooff_3col.stl, 2510_Board_Fan_Mount.stl, 30xx_Board_Fan_Mount.stl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]
2026-10-24 V9.1 Mount Standoff for NH36
    Replace the Mount Standoff for the NH36. The old one pushed against the carriage mount.
